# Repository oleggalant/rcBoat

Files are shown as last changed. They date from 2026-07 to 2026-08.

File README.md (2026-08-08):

# rcBoat — a 3D-printed RC catamaran, build it yourself

A weekend (or two) DIY project: a long-range radio-controlled boat with a
3D-printed hull and **four empty cola bottles** as floats. build it yourself! it only takes one weekend on the hull and floats, one
weekend on the electronics and the first drive.

```
Phone (Chrome, Web Bluetooth joystick) → BLE → transmitter ESP32-C3
      → ESP-NOW (Long-Range PHY) → boat ESP32-C3 → dual ESCs
```

## What you need

- A 3D printer (STL files: see [`stls/`](stls/))
- 4 empty 1.5–2 L cola bottles, rinsed out, labels off, caps on
- 2x ESP32-C3-DevKitM-1 boards (one for the boat, one for the handheld
  transmitter) — the transmitter board should have an external antenna
- 2x brushless motors + ESCs, propellers
- A GY-271 compass module for the boat, for heading-hold (see chip note below)
- A phone with Chrome (Android or desktop) for the controller page
- Small Li-ion/LiPo or USB power bank for the transmitter; a battery + BEC
  (or separate 5V supply) for the boat electronics

## Weekend 1 — hull & floats

Print the hull parts, mount the bottles as floats, fit the motor/ESC
mounts:

- [`stls/`](stls/) — STL files for the printed parts (motor mount, bottle
  T-connector, turnbuckle)
- [`photos/`](photos/) — build photos and reference pictures

*(Photos to follow.)*

## Weekend 2 — electronics & first drive

This is the part that's already built and tested. See below.

### Build & flash

Two firmwares, one per board (both ESP32-C3-DevKitM-1):

```bash
pio run -e boat -t upload
pio run -e transmitter -t upload
pio device monitor            # 115200 baud
```

With both boards plugged in at once, pass `--upload-port COMx` / `--monitor-port COMx`.

### Joystick page (`web/joystick.html`)

Web Bluetooth requires HTTPS, so host the file on any HTTPS static host
(GitHub Pages is the easy path) and open it in Chrome. Tap **Connect** and
pick `rcBoatTx`. No internet is needed after the page loads — keep the tab
open on the water.

Two control layouts, switchable in the page (saved per-device):
- **1-stick**: single joystick, horizontal = turn, vertical = thrust
- good for fishing if phone held in one hand,fishing rod in other
- **2-hand**: landscape, turn slider on the left, thrust slider on the right
  — good for racing/casual sailing and water watching(needs an external camera)

### Compass wiring (GY-271, boat only)

| GY-271 pin | ESP32-C3 pin |
|---|---|
| VCC | 3V3 |
| GND | GND |
| SCL | GPIO7 |
| SDA | GPIO6 |
| DRDY / INT | not connected |

GPIO8/9 are deliberately avoided: GPIO8 is hardwired to the DevKitM-1's
onboard addressable RGB LED (which can interfere with I2C on that pin), and
GPIO9 is a boot-strapping pin — GPIO6/7 are plain, unencumbered GPIOs.

Mount it as far as practical from the ESCs and motor wiring — motor current
is the most likely source of magnetic interference — and roughly level.

**Chip note**: boards sold as "GY-271 QMC5883L" increasingly ship a newer,
pin-similar chip called **QMC5883P** instead — same footprint, different I2C
address (`0x2C` vs the older `0x0D`) and register map. This firmware targets
QMC5883P (via the `Adafruit_QMC5883P` library). If your board turns out to
have a genuine QMC5883L or an HMC5883L clone instead, flash
`pio run -e compass_test -t upload` and open `pio device monitor` — it scans
the whole I2C bus, fingerprints whichever of the three chips is present
(chip-ID register match, not just an address guess), and streams live raw
X/Y/Z once identified, all without the rest of the radio stack running.

**Wiring debug on the water**: `web/trace.html` (also linked as "Trace" from
the main controller page) connects over the same BLE link and shows a live
readout — RSSI, heading, calibration state, raw compass X/Y, and which I2C
address last ACKed — plus a scrolling log of every telemetry update, with no
serial cable needed.

### Settings panel (⚙ button on the joystick page)

- **Heading Hold** — while driving forward with the turn stick centered, the
  boat locks onto its current heading and corrects for drift (prop torque,
  wind, current) — like an RC "heading-hold gyro". Turning always overrides
  it immediately; releasing the stick locks onto the new heading. Requires
  the compass to be calibrated first.
- **Min throttle PWM** — a response floor: any nonzero throttle jumps
  straight to this PWM instead of crawling up from 1000 µs, where the prop
  may not even be spinning yet.
- **Calibrate Compass** — rotate the boat through a full circle (a figure-8
  works well) for about 20 seconds, away from other metal/magnets, then tap
  Save. The progress bar fills as it sees more of the circle. Calibration is
  stored on the boat and survives reboots.

If heading-hold ever fights a turn instead of helping it, the compass's
mounting orientation has the sign backwards for this particular module —
flip `PID_SIGN` in `include/config.h` from `1` to `-1` and reflash the boat.

### Radio settings (`include/config.h`)

- `ESPNOW_CHANNEL` — must match on both boards.
- `ESPNOW_USE_LR` — 1 enables Espressif Long-Range PHY (~2–4× range; both
  boards must agree or the link is silently dead). Set 0 to A/B-test range.

### Failsafes

- Boat cuts motors to idle if no control packet is recived for 500 ms (`WATCHDOG_MS`).
- Transmitter sends neutral signals if the phone disconnects or stops writing for
  1 s (`BLE_WATCHDOG_MS`) — the page heartbeats every 250 ms.
- Transmitter re-enters discovery if the boat is silent for 5 s.
- ESCs are held at 1000 µs for 3 s at boot (arming), same as the original.

## Safety notes (worth a read )

- First runs: **props off**. Verify pairing, joystick response, and that
  killing the transmitter or closing the phone tab actually stops the boat.
- Keep hands clear of props once they're on — arm the ESCs, then don't touch.
- Test failsafes deliberately: turn off the transmitter, close the browser
  tab, walk out of BLE range — in every case the boat should stop.
- Water testing: !carefully! calm/shallow water first, and a plan for
  retrieving the boat if the link ever does drop.

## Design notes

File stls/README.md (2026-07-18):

# Printed parts

STL files for the 3D-printed hull hardware:

- `motor.stl` — motor mount
- `t-connector.stl` — T-connector joining a cola-bottle float to the frame
- `turnbuckle.stl` — tensioner/rigging piece holding the floats to the frame

*(Print settings and photos to follow.)*

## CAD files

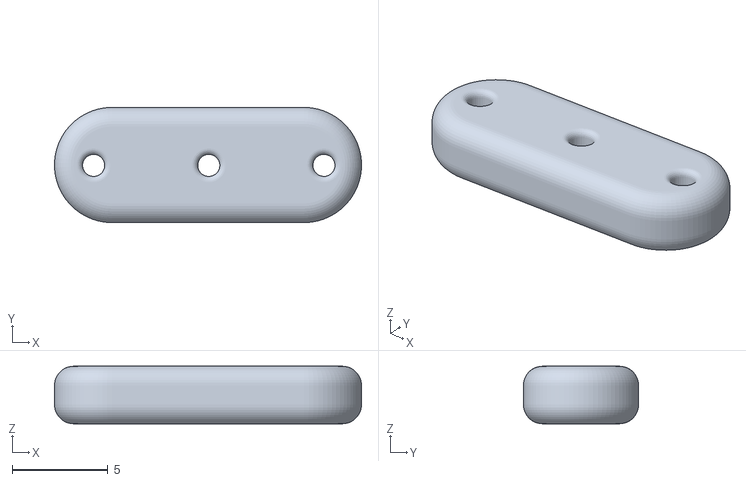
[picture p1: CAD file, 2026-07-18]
stls/turnbuckle.stl
16.0 x 6.00 x 3.00

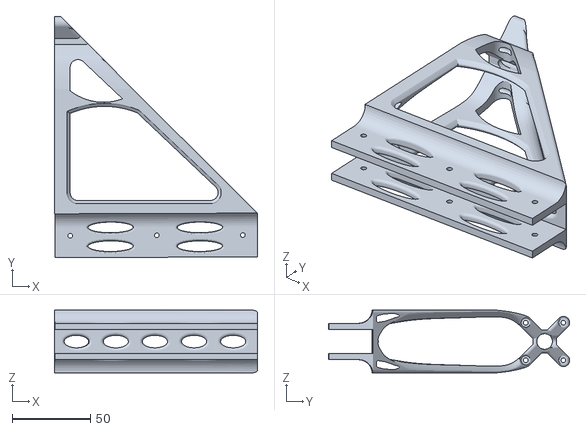
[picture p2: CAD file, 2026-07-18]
stls/motor.stl
129.7 x 154.2 x 40.0

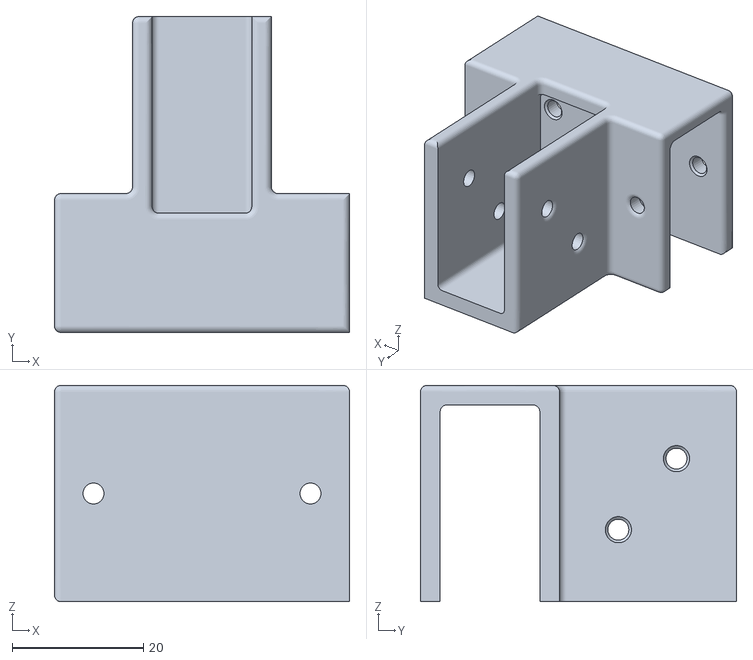
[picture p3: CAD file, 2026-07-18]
stls/t-connector.stl
45.0 x 48.2 x 33.0

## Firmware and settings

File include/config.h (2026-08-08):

#pragma once

// ── Boat: ESC outputs (same wiring as the original rcBoat) ──────────────────
#define MOTOR_LEFT_PIN   1
#define MOTOR_RIGHT_PIN  5

// Standard hobby ESC PWM range (microseconds)
#define ESC_MIN_US       1000   // stopped / armed
#define ESC_MAX_US       2000   // full throttle

// Time to hold ESC_MIN_US on boot so ESCs complete arming sequence
#define ESC_ARM_DELAY_MS 3000

// Boat: stop motors if no control packet received for this long (ms)
#define WATCHDOG_MS      500

// ── Radio link ───────────────────────────────────────────────────────────────
#define ESPNOW_CHANNEL   6      // both ends MUST match
#define ESPNOW_USE_LR    1      // 1 = Espressif Long-Range PHY (both ends must
                                // agree!), 0 = standard 802.11bgn for A/B tests
#define HEARTBEAT_MS     50     // TX resends last control at 20 Hz
#define TELEMETRY_MS     2000   // boat -> TX RSSI report period
#define DISCOVERY_MS     500    // TX pairing broadcast period
#define LINK_TIMEOUT_MS  5000   // TX: no packet from boat -> back to discovery

// ── Transmitter: BLE ─────────────────────────────────────────────────────────
#define BLE_DEVICE_NAME  "rcBoatTx"
// Neutralize the boat if the phone stops writing for this long. The web page
// heartbeats every 250 ms, so this only trips on a hung/backgrounded tab.
#define BLE_WATCHDOG_MS  1000

// ── Boat: compass (GY-271 QMC5883L) ─────────────────────────────────────────
// GPIO8 avoided: it's hardwired to the ESP32-C3-DevKitM-1's onboard
// addressable RGB LED, which can interfere with I2C on that pin. GPIO9
// avoided too: it's a boot-strapping pin. GPIO6/7 are plain, unencumbered
// GPIOs — free alongside motors on GPIO1/5, flash on 11-17, USB on 18/19.
#define COMPASS_SDA_PIN   6
#define COMPASS_SCL_PIN   7
#define COMPASS_READ_MS   50    // I2C read/update rate

// Heading-hold PID (yaw correction, output fraction of full yaw authority).
// Conservative starting point — tune on the water.
#define PID_KP               0.02f
#define PID_KI               0.0f
#define PID_KD               0.01f
#define PID_MAX_CORRECTION   0.3f   // clamp: never out-muscle manual steering
#define HEADING_YAW_DEADBAND 0.05f  // |yaw| below this counts as "centered"
// Whether the compass's derived heading increases when the boat turns right
// depends on how the module is physically mounted — can't be known until it's
// bench-tested (twist the board by hand, watch the printed correction). Flip
// to -1 if the correction reinforces drift instead of opposing it.
#define PID_SIGN             1

// Default settings (overridden by whatever's saved in boat Preferences)
#define DEFAULT_MIN_RUN_US        1150  // throttle response floor (µs)
#define DEFAULT_HEADING_HOLD_ON   0     // stays off until compass is calibrated

// Telemetry cadence while a compass calibration is in progress (ms) — faster
// than the normal TELEMETRY_MS so the phone's progress bar feels live.
#define TELEMETRY_CAL_MS  300

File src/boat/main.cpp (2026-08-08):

// Boat firmware: ESP-NOW control in -> compass heading-hold -> differential
// ESC PWM out. Failsafe semantics match the original WiFi rcBoat: 3 s ESC arm
// at boot, motors cut to idle if no control packet arrives within WATCHDOG_MS.

#include <Arduino.h>
#include <Preferences.h>
#include "config.h"
#include "common/espnow_link.h"
#include "protocol.h"
#include "motors.h"
#include "compass.h"
#include "heading_pid.h"

static Preferences g_settingsPrefs;
static uint16_t g_minRunUs = DEFAULT_MIN_RUN_US;
static bool g_headingHoldEnabled = DEFAULT_HEADING_HOLD_ON;
static uint32_t g_calJustSavedUntil = 0;

static void loadSettings() {
    g_settingsPrefs.begin("settings", true);
    g_minRunUs = g_settingsPrefs.getUShort("minRunUs", DEFAULT_MIN_RUN_US);
    g_headingHoldEnabled = g_settingsPrefs.getBool("hHold", DEFAULT_HEADING_HOLD_ON);
    g_settingsPrefs.end();
}

static void saveSettings() {
    g_settingsPrefs.begin("settings", false);
    g_settingsPrefs.putUShort("minRunUs", g_minRunUs);
    g_settingsPrefs.putBool("hHold", g_headingHoldEnabled);
    g_settingsPrefs.end();
}

// Remap [0,1] throttle onto a floor so any nonzero stick jumps straight to
// g_minRunUs instead of crawling up from ESC_MIN_US, where the prop may not
// even be spinning yet. motors.cpp's mixing math is left untouched.
static float applyThrottleFloor(float throttle) {
    if (throttle <= 0.0f) return 0.0f;
    float floorFrac = (g_minRunUs - ESC_MIN_US) / (float)(ESC_MAX_US - ESC_MIN_US);
    floorFrac = constrain(floorFrac, 0.0f, 1.0f);
    return floorFrac + throttle * (1.0f - floorFrac);
}

void setup() {
    Serial.begin(115200);
    motorsInit();               // blocks ESC_ARM_DELAY_MS for arming
    loadSettings();
    compassInit();
    espnowLinkInit(true);
}

void loop() {
    espnowLinkService();
    const uint32_t now = millis();

    if (espnowLinkPaired()) {
        int16_t x, y;
        if (espnowLinkGetControl(x, y)) {
            float throttleF = y / 1000.0f;
            float yaw = headingHoldUpdate(throttleF, x / 1000.0f, g_headingHoldEnabled);
            motorsSet(applyThrottleFloor(throttleF), yaw);

            static uint32_t lastLog = 0;
            if (now - lastLog >= 1000) {
                lastLog = now;
                Serial.printf("Control: x=%d y=%d rssi=%d heading=%d\n",
                              x, y, espnowLinkLastRxRssi(), compassHeadingDeg());
            }
        }
    }

    compassUpdate();

    // Settings from the phone (throttle floor / heading-hold toggle)
    uint16_t newMinRunUs; bool newHeadingHold;
    if (espnowLinkGetSettings(newMinRunUs, newHeadingHold)) {
        g_minRunUs = newMinRunUs;
        g_headingHoldEnabled = newHeadingHold;
        saveSettings();
        Serial.printf("Settings: minRunUs=%u headingHold=%d\n", g_minRunUs, g_headingHoldEnabled);
    }

    // Compass calibration commands from the phone
    uint8_t calCmd;
    if (espnowLinkGetCalCommand(calCmd)) {
        switch (calCmd) {
            case CAL_START:
                compassCalStart();
                break;
            case CAL_SAVE:
                if (compassCalStop(true)) g_calJustSavedUntil = now + 3000;
                break;
            case CAL_CANCEL:
                compassCalStop(false);
                break;
        }
    }

    // Watchdog: link silent -> cut motors (identical to the WiFi version)
    static bool wdTripped = false;
    const uint32_t lastControl = espnowLinkLastControlMs();
    if (lastControl > 0 && now - lastControl > WATCHDOG_MS) {
        motorsStop();
        if (!wdTripped) {
            wdTripped = true;
            Serial.println("Watchdog: link lost, motors stopped");
        }
    } else {
        wdTripped = false;
    }

    static uint32_t lastTelemetry = 0;
    uint32_t telemetryInterval = compassCalActive() ? TELEMETRY_CAL_MS : TELEMETRY_MS;
    if (espnowLinkPaired() && now - lastTelemetry >= telemetryInterval) {
        lastTelemetry = now;
        uint8_t calState = CAL_STATE_IDLE;
        if (compassCalActive()) calState = CAL_STATE_CALIBRATING;
        else if (now < g_calJustSavedUntil) calState = CAL_STATE_SAVED;
        int16_t rawX, rawY;
        compassRawXY(rawX, rawY);
        espnowLinkSendTelemetry(espnowLinkLastRxRssi(), espnowLinkTakeLossPct(),
                                 (int16_t)compassHeadingDeg(), calState,
                                 compassCalCoveragePct(), rawX, rawY, compassI2cAddr());
    }
}

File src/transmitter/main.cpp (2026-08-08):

// Transmitter firmware: BLE joystick in (phone) -> ESP-NOW control out (boat).
//
// Failsafes:
//  - BLE disconnect or no BLE write for BLE_WATCHDOG_MS -> send neutral (0,0).
//  - Control is retransmitted every HEARTBEAT_MS regardless of change, so the
//    boat's 500 ms watchdog stays fed while the stick is held steady.
//  - No packet from the boat for LINK_TIMEOUT_MS -> back to discovery.

#include <Arduino.h>
#include "config.h"
#include "common/espnow_link.h"
#include "protocol.h"
#include "ble_uart.h"

void setup() {
    Serial.begin(115200);
    espnowLinkInit(false);      // WiFi/ESP-NOW before NimBLE for clean coex init
    bleUartInit();
}

void loop() {
    espnowLinkService();
    const uint32_t now = millis();

    // Pairing state machine
    if (!espnowLinkPaired()) {
        static uint32_t lastDiscover = 0;
        if (now - lastDiscover >= DISCOVERY_MS) {
            lastDiscover = now;
            espnowLinkSendDiscover();
        }
    } else if (now - espnowLinkLastRxMs() > LINK_TIMEOUT_MS) {
        Serial.println("Link: boat silent, re-discovering");
        espnowLinkResetPairing();
        bleUartNotifyTelemetry(0, -1, CAL_STATE_IDLE, 0, 0, 0, 0);   // phone bars go dark
    }

    // Control values with BLE failsafe
    int16_t x, y;
    bool fresh = bleUartGetControl(x, y);
    const uint32_t lastWrite = bleUartLastWriteMs();
    const bool bleOk = bleUartConnected() && lastWrite > 0 &&
                       now - lastWrite <= BLE_WATCHDOG_MS;
    if (!bleOk) {
        x = 0;
        y = 0;
    }

    // Send immediately on change, otherwise heartbeat the last values
    static uint32_t lastSend = 0;
    if (espnowLinkPaired() && (fresh || now - lastSend >= HEARTBEAT_MS)) {
        lastSend = now;
        espnowLinkSendControl(x, y);
    }

    // Forward boat telemetry to the phone
    int8_t rssi;
    uint8_t lossPct, calState, calPct;
    int16_t heading, rawX, rawY;
    uint8_t i2cAddr;
    if (espnowLinkGetTelemetry(rssi, lossPct, heading, calState, calPct, rawX, rawY, i2cAddr)) {
        bleUartNotifyTelemetry(rssi, heading, calState, calPct, rawX, rawY, i2cAddr);
        Serial.printf("Telemetry: boat rssi %d dBm, loss %u%%, heading %d, cal %u/%u%%, raw %d,%d, i2cAddr 0x%02X\n",
                      rssi, lossPct, heading, calState, calPct, rawX, rawY, i2cAddr);
    }

    // Settings/calibration commands from the phone (one-shot, sent immediately
    // — ESP-NOW's unicast ACK/retry is enough, no heartbeat needed)
    uint16_t minRunUs; bool headingHoldEnabled;
    if (espnowLinkPaired() && bleUartGetSettings(minRunUs, headingHoldEnabled)) {
        espnowLinkSendSettings(minRunUs, headingHoldEnabled);
    }
    uint8_t calCmd;
    if (espnowLinkPaired() && bleUartGetCalCommand(calCmd)) {
        espnowLinkSendCalCommand(calCmd);
    }
}

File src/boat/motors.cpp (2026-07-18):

#include "motors.h"
#include <Arduino.h>
#include <ESP32Servo.h>
#include "config.h"

static Servo leftMotor;
static Servo rightMotor;

void motorsInit() {
    ESP32PWM::allocateTimer(0);
    ESP32PWM::allocateTimer(1);
    ESP32PWM::allocateTimer(2);
    ESP32PWM::allocateTimer(3);
    leftMotor.setPeriodHertz(50);
    rightMotor.setPeriodHertz(50);
    leftMotor.attach(MOTOR_LEFT_PIN,  ESC_MIN_US, ESC_MAX_US);
    rightMotor.attach(MOTOR_RIGHT_PIN, ESC_MIN_US, ESC_MAX_US);
    motorsStop();
    Serial.println("Motors: arming ESCs...");
    delay(ESC_ARM_DELAY_MS);
    Serial.println("Motors: ready");
}

void motorsSet(float throttle, float yaw) {
    float left  = constrain(throttle + yaw, 0.0f, 1.0f);
    float right = constrain(throttle - yaw, 0.0f, 1.0f);
    leftMotor.writeMicroseconds(ESC_MIN_US  + (int)(left  * (ESC_MAX_US - ESC_MIN_US)));
    rightMotor.writeMicroseconds(ESC_MIN_US + (int)(right * (ESC_MAX_US - ESC_MIN_US)));
}

void motorsStop() {
    leftMotor.writeMicroseconds(ESC_MIN_US);
    rightMotor.writeMicroseconds(ESC_MIN_US);
}

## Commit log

2026-07-18 Initial commit: ESP-NOW long-range RC boat
    Phone (Web Bluetooth joystick) -> BLE -> transmitter ESP32-C3
    -> ESP-NOW (LR PHY) -> boat ESP32-C3 -> dual ESCs.
    Two PlatformIO envs (transmitter, boat), shared binary protocol,
    broadcast auto-pairing locked to unicast, watchdog failsafes,
    web controller with 1-stick and 2-hand modes.
    [ble_uart.cpp, config.h, espnow_link.cpp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]
2026-07-18 Reframe README as a parent-child weekend build; add hull/ and photos/ placeholders
    Weekend 1 (hull + 4 cola-bottle floats) and weekend 2 (electronics,
    already built) split, plus safety notes for testing with kids.
2026-07-18 Add printed-part STLs, drop hull/ placeholder in favor of stls/
    motor mount, bottle T-connector, turnbuckle.
    [motor.stl, t-connector.stl, turnbuckle.stl]
2026-08-08 Add compass heading-hold, throttle floor, and a settings panel
    GY-271 QMC5883L on the boat (GPIO8/9 I2C) drives a heading-hold PID:
    whenever throttle is applied and the turn stick is centered, the boat
    locks onto its current heading and corrects for drift, like an RC
    heading-hold gyro. Turning always overrides it immediately.
    Adds a phone-driven remote calibration flow (rotate the boat, save --
    no serial cable needed on the water) and a throttle response floor so
    small stick inputs don't sit in a dead zone. New settings/calibration
    BLE characteristics on the transmitter and matching ESP-NOW packet
    types (protocol bumped to v2); a settings panel on the web controller
    exposes heading readout,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
    [ble_uart.cpp, compass.cpp, config.h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]
2026-08-08 Add Show Trim toggle to settings panel
    Trim adds a static yaw offset that feeds into the same value
    heading-hold checks for a centered stick, so a nonzero trim can
    silently block heading-hold from engaging. Hiding trim now zeroes it
    instead of just removing the buttons.
2026-08-08 Add compass trace page and raw X/Y telemetry for wiring debugging
    TelemetryPacket gains rawX/rawY magnetometer counts, sent every cycle
    regardless of calibration state (protocol bumped to v3). New
    web/trace.html connects over the same BLE link and shows a live
    readout + scrolling log of everything the boat reports -- lets you
    watch raw compass values (and RSSI/heading/cal state) update in real
    time while debugging I2C wiring, with no serial cable needed. Linked
    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
2026-08-08 Report the live I2C address, not just presence, in telemetry
    TelemetryPacket now carries the address that ACKed the last probe
    (0x0D = QMC5883L, 0x1E = HMC5883L-clone address, 0 = nothing) instead
    of a plain found/not-found bool -- lets the trace page tell "wrong
    chip" apart from "no chip" apart from "chip present but stuck"
    without a fresh boot/serial capture. Protocol bumped to v4.
    [ble_uart.cpp, compass.cpp, espnow_link.cpp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]
2026-08-08 Move compass I2C off GPIO8/9 to avoid onboard LED / strapping conflict
    GPIO8 is hardwired to the ESP32-C3-DevKitM-1 onboard addressable RGB
    LED, which was very likely the reason the I2C bus showed nothing at
    either candidate address (trace page: i2c:0) despite good wiring
    otherwise. GPIO9 is also a boot-strapping pin. Moved SDA/SCL to
    GPIO6/7, which are plain, unencumbered GPIOs.
    [config.h]
2026-08-08 Fix compass: many "GY-271 QMC5883L" boards actually ship QMC5883P
    The I2C bus scan found the chip at 0x2C, not 0x0D or 0x1E -- the
    board has the newer QMC5883P instead of the QMC5883L its silkscreen
    implies. Different address, different register map. Switched the
    driver from QMC5883LCompass to Adafruit_QMC5883P and moved hard-iron
    calibration application into compass.cpp directly, since the new
    library has no offset/scale hooks of its own.
    Also adds a standalone compass_test env/firmware (no ESP-NOW/BLE) that
    scans the whole bus and fingerprints whichever of the three chips
    ("GY-271" has shipped with QMC5883L, HMC5883L-clones, and now
    QMC5883P) is actually present, streaming live raw X/Y/Z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
    [compass.cpp, main.cpp, protocol.h]
